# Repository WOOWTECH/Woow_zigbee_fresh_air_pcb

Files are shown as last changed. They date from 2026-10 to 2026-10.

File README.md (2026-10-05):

# Woow Zigbee 新風控制器 PCB（WO_30109）



220V 供電、4 路繼電器輸出的 Zigbee 新風（換氣扇）控制板。V3.0 起由一顆 **ESP32-C6** 同時負責 Zigbee 3.0 連網與控制，433MHz 遙控由 **SYN480R** 接收、ESP32 解碼（V2.0 以前是 STM32F103＋Tuya ZS3L＋EPA09-4D 模組）。

這個 repo 是把原設計 **V1.3**（Altium，外包設計）完整轉成 **KiCad 10**，用 git 做版控，並在 **V2.0** 修掉安規問題。

| 版本 | 狀態 | 說明 |
|---|---|---|
| `v1.3` | 參考用，**不可量產** | 原設計忠實重繪（原理圖＋PCB）。市電與低壓 GND 只隔 0.127mm。（`v1.3-baseline` 只含原理圖） |
| `v2.0` | **DRC 0 錯誤**（已合併 `main`） | 市電隔離 ≥6.4mm、保險絲＋壓敏電阻、降壓電源、Zigbee 串口 |
| `v3.0` | ERC/DRC 0；韌體 CI 綠燈 | ESP32-C6 單晶片 Zigbee＋SYN480R 433MHz，全部主料 JLC 可貼；市電區沿用 V2.0。見 [CHANGELOG](CHANGELOG.md#30--esp32-c6-單晶片syn480r) |
| `v3.4` | **目前版本**（ERC/DRC 0），**待打樣實測** | 照外殼 4-02-3（88×72×59 導軌盒）放回原板框：DI 2.54mm、NFC 外接 FPC 天線、P2 改測試點。見 [V3.4 驗證報告](docs/verification/V3.4.md) |
| `v3.3` | ⛔ 放不進外殼（板子加高到 107mm） | 加 NFC 設定介面（ST25DV04KC＋板上印刷線圈），J5 改到左側板邊。見 [V3.3 驗證報告](docs/verification/V3.3.md) |
| `v3.2` | ⛔ 放不進外殼（板子加高到 93mm） | 上緣左半段加長 10mm（L 形）加 4 路光耦 DI（乾接點／5–24VDC，NPN／PNP）、拿掉指撥。見 [V3.2 驗證報告](docs/verification/V3.2.md)（含 J5 接線） |
| `v3.1` | 只換值、不改佈線；ERC/DRC 0 | 433 匹配重新選值（失配 8–13dB → 3–5.3dB）、繼電器 PWM 降壓保持（取消 ≤3 顆限制）、續流改 Schottky、CPL 角度修正。見 [V3.1 驗證報告](docs/verification/V3.1.md) |

| V3.0 正面（零件面） | V3.0 背面 |
|---|---|
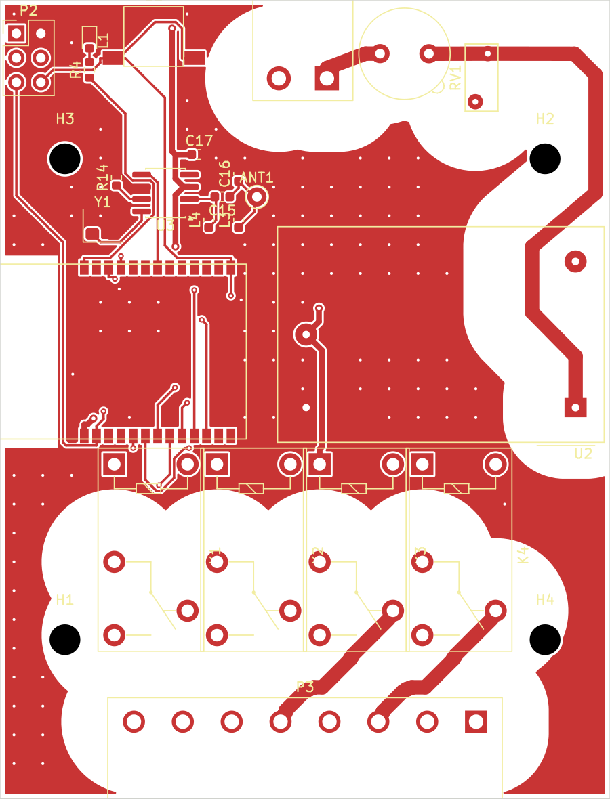
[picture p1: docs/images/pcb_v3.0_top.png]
PCB V3.0 正面
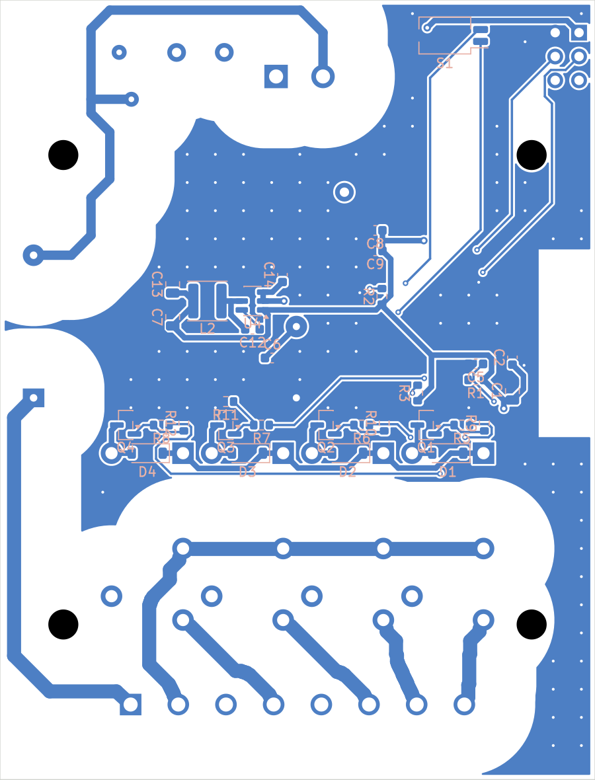
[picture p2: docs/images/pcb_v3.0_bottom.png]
PCB V3.0 背面
|  |  |

背面圖中藍色是 GND 鋪銅，白色帶是市電周圍 6.4mm 的安全帶（DRC 規則自動退讓）。完整原理圖：[V3.0](docs/images/schematic_v3.0.png)／[V2.0](docs/images/schematic_v2.0.png)。V3.0 左緣是 ESP32-C6 模組（天線端下方禁銅），左上是 SYN480R 433MHz 接收。

---

## 目錄

- [電路架構](#電路架構)
- [V1.3 → V2.0 改了什麼](#v13--v20-改了什麼)
- [安規隔離設計](#安規隔離設計)
- [Repo 結構](#repo-結構)
- [怎麼改設計（範例）](#怎麼改設計範例)
- [版本控制流程](#版本控制流程)
- [自動檢查（CI）](#自動檢查ci)
- [設計驗證報告](docs/verification/README.md)
- [主要料件](#主要料件)
- [已知限制與待辦](#已知限制與待辦)

---

## 電路架構

（V3.0；V2.0 以前低壓區是 STM32F103＋Tuya ZS3L＋EPA09-4D）

```mermaid
flowchart LR
    subgraph MAINS["⚡ 市電區（230VAC）"]
        P1["P1 市電輸入<br/>L / N"] --> F1["F1 保險絲<br/>T3.15A"]
        F1 --> RV1["RV1 壓敏電阻<br/>07D471K"]
        F1 --> IRM["U2 IRM-02-12<br/>AC→12V 2W<br/>（4.2kV 隔離）"]
        F1 -->|"P3.1 AC_L 輸出"| P3
        K["K1–K4 繼電器接點<br/>COM / NO / NC"] --> P3["P3 8P 輸出端子<br/>接風扇／閥"]
    end
    subgraph SELV["🔋 低壓區（12V / 3.3V）"]
        IRM -->|"+12V"| BUCK["U4 AP63203<br/>12V→3.3V 降壓"]
        IRM -->|"+12V"| COIL["繼電器線圈<br/>Q1–Q4 Si2302 驅動"]
        BUCK -->|"+3V3"| MCU["U1 ESP32-C6-WROOM-1<br/>Zigbee 3.0＋控制（V3.0）"]
        BUCK --> RF["U3 SYN480R<br/>433MHz ASK 接收"]
        ANT["ANT1 17.3cm 天線"] --> RF
        RF -->|"RF_DATA → IO23<br/>韌體解 EV1527"| MCU
        MCU -->|"Relay_1–4（IO6/7/0/1）"| COIL
        UI["B1 按鍵(IO9 BOOT) / S1 指撥 / L1 燈 / P2 燒錄座"] --- MCU
    end
    COIL -.->|"線圈-接點 加強絕緣"| K
```

### 電源預算（12V，IRM-02-12 額定 167mA）

| 負載 | V1.3 | V2.0 |
|---|---|---|
| 4 顆繼電器全吸（33.3mA × 4） | 133mA | 133mA |
| 3.3V 側（約 40mA） | 線性穩壓：12V 端也是 ~45mA | 降壓：12V 端約 13mA |
| **合計** | **~178mA（超過額定）** | **~146mA（在額定內）** |

---

## V1.3 → V2.0 改了什麼

```mermaid
flowchart TB
    A["V1.3 問題"] --> B1["市電離 GND 鋪銅 0.127mm"]
    A --> B2["AC 入口沒保險絲、沒壓敏電阻"]
    A --> B3["LM1117 線性穩壓：發熱、MLCC 不穩、12V 預算超標"]
    A --> B4["ZS3L 只用 GPIO，UART 沒接"]
    B1 --> C1["DRC 規則：市電↔低壓 ≥6.4mm<br/>鋪銅自動退讓、低壓元件移出安全帶"]
    B2 --> C2["F1 T3.15A ＋ RV1 07D471K"]
    B3 --> C3["AP63203 同步降壓（陶瓷電容穩定、耐 32V）"]
    B4 --> C4["TXD→PA10、RXD←PA9、RST←PB1"]
```

完整清單見 [CHANGELOG.md](CHANGELOG.md)，原設計審查見 [docs/review](docs/review)。

---

## 安規隔離設計

依 IEC 60664-1（230VAC、過電壓類別 II、汙染等級 2）設定，寫在 [`WO30109_FreshAir.kicad_dru`](hardware/WO30109_FreshAir/WO30109_FreshAir.kicad_dru)，KiCad DRC 與鋪銅都會自動遵守：

| 位置 | 要求 | V1.3 實測 | V2.0 |
|---|---|---|---|
| 市電 ↔ 低壓（含 GND 鋪銅） | ≥ 6.4mm（加強絕緣；與 G5Q 繼電器本身設計值相同） | **0.127mm** | ≥ 6.4mm |
| 市電不同網路之間（L-N、各路輸出） | ≥ 1.5mm（功能絕緣；G5Q 相鄰接點腳本身 1.67mm） | 0.5mm | ≥ 1.5mm |
| 銅到板邊 | ≥ 0.5mm | 0.26mm | ≥ 0.5mm |
| 固定孔（非金屬化）到市電 | ≥ 2.3mm（M3 螺絲頭多出孔外 1.15mm＋餘量）；**須用尼龍螺絲** | 1.77mm | 2.40–2.90mm |

```mermaid
flowchart LR
    L["市電銅箔<br/>AC_L / AC_N / DO_*"] ---|"≥ 1.5mm"| L2["另一條市電銅箔"]
    L ---|"≥ 6.4mm 安全帶<br/>（不得有任何低壓銅）"| S["低壓銅箔<br/>GND / 3.3V / 12V / 訊號"]
```

**怎麼確認**：在 KiCad 開 PCB → 檢查 → 設計規則檢查（DRC），或命令列：

```bash
kicad-cli pcb drc --severity-error hardware/WO30109_FreshAir/WO30109_FreshAir.kicad_pcb
```

---

## Repo 結構

```text
.
├── hardware/
│   ├── WO30109_FreshAir/          # KiCad 專案（用 KiCad 10 開 .kicad_pro）
│   │   ├── WO30109_FreshAir.kicad_sch   # 原理圖（由 scripts 產生）
│   │   ├── WO30109_FreshAir.kicad_pcb   # PCB
│   │   ├── WO30109_FreshAir.kicad_dru   # 安規 DRC 規則
│   │   ├── WO30109_FreshAir.kicad_jobset # 一鍵產出（ERC/DRC/Gerber/BOM/STEP）
│   │   └── sym-lib-table / fp-lib-table # 指向 ../lib 的專案庫
│   └── lib/
│       ├── WOOW.kicad_sym         # 自訂符號：ZS3L、EPA09-4D
│       ├── WOOW.pretty/           # 自訂封裝（焊盤量測自原板）
│       └── WOOW.3dshapes/         # 自訂 3D 模型
├── docs/verification/             # 設計驗證報告
├── scripts/
│   ├── design.py                  # ★ 電路唯一來源：零件、腳位、網路、改版差異
│   ├── gen_schematic.py           # design.py → .kicad_sch
│   ├── make_footprints.py         # 產生 WOOW.pretty
│   ├── import_v13_pcb.py          # 原 Gerber → KiCad PCB（需原始 Gerber，不公開）
│   ├── upgrade_v20_pcb.py         # V2.0 擺件與市電入口走線
│   ├── mains_router.py            # 雙層格點佈線器（市電間 1.5mm、對低壓 6.4mm）
│   ├── route_v20.py               # Freerouting 低壓佈線 + 鋪銅
│   ├── route_leftovers.py         # 補繞 Freerouting 沒繞通的線
│   ├── build_v20.sh               # ★ 一鍵重建 V2.0 PCB
│   ├── build_v30.sh               # ★ 一鍵重建 V3.0 PCB（從標籤 v2.0）
│   ├── build_v34.sh               # ★ 一鍵重建 V3.4 PCB（目前版本；從 V3.1 換件擺件 → Freerouting）
│   ├── upgrade_v34_pcb.py         # V3.4 換件、擺件、套網表、拆低壓走線
│   ├── upgrade_v32_pcb.py         # V3.2／V3.3 PCB（已作廢：放不進外殼）
│   ├── nfc_coil.py                # NFC 印刷線圈電感與調諧電容計算
│   ├── make_jlc_files.py          # ★ JLC 下單檔：Gerber zip、BOM、CPL（含 JLC 旋轉修正）
│   ├── drc_summary.py             # DRC 結果摘要
│   ├── add_stitching.py           # GND 縫合過孔
│   ├── make_3d_models.py          # 自訂零件 3D 模型（STEP）
│   └── assign_3d.py               # 3D 模型掛到封裝
├── sim/                           # SPICE 模擬（ngspice）
├── docs/review/                   # 設計審查報告
├── .github/workflows/kicad-ci.yml # 自動 ERC / DRC / 生產檔
├── CHANGELOG.md
└── README.md
```

---

## 怎麼改設計（範例）

原理圖由 `scripts/design.py` 產生，**改電路請改 design.py，不要直接在 KiCad 手改原理圖**（下次產生會被蓋掉）。PCB 可以直接在 KiCad 改。

### 範例 1：把 R4（LED 限流）從 100Ω 改成 220Ω

```python
# scripts/design.py
add("R4", "Device:R", "220R", R0603, "C22962", {"1": led_net, "2": "LED_A"})
```

```bash
python scripts/gen_schematic.py 2.0          # 重新產生原理圖
kicad-cli sch erc hardware/WO30109_FreshAir/WO30109_FreshAir.kicad_sch
# 開 KiCad PCB → 工具 → 從原理圖更新 PCB（F8）
git switch -c fix/led-resistor
git commit -am "fix: R4 改 220R，降低 LED 亮度"
git push -u origin fix/led-resistor && gh pr create
```

### 範例 2：在 KiCad 圖形介面裡用 Git

KiCad 9 起專案管理器內建 Git（檔案樹會顯示修改狀態、可 commit / push / pull / 切分支）。KiCad 9.0.0 的 push/pull 帳密處理曾有回報問題，建議 commit 用 KiCad、push 用命令列或 `gh`：

1. 用 KiCad 開 `hardware/WO30109_FreshAir/WO30109_FreshAir.kicad_pro`
2. 左側檔案樹按右鍵 → **Git** → Commit / Push / Switch branch
3. 偏好設定 → Version Control 可設定作者與遠端更新頻率

### 範例 3：重建整片 V2.0 PCB

```mermaid
flowchart LR
    A["原 V1.3 Gerber<br/>（不公開）"] --> B["import_v13_pcb.py<br/>銅箔→KiCad、焊盤對位"]
    D["design.py<br/>V2.0 網表"] --> B
    B --> C["upgrade_v20_pcb.py<br/>擺件、市電入口"]
    C --> E["mains_router.py<br/>繼電器輸出 DO_*"]
    E --> F["Freerouting<br/>低壓網路"]
    F --> G["route_leftovers.py<br/>補線"]
    G --> H["鋪銅（DRC 規則退讓）"]
    H --> I["DRC 0 錯誤"]
```

```bash
# 需要 KiCad 10、Java 17、xvfb-run、Freerouting 1.9 jar、kicad-sch-api
ORIG_GERBER=/path/to/V1.3_gerber ./scripts/build_v20.sh
```

Freerouting 每次結果不完全一樣；跑完一定看最後的 DRC 摘要，`errors: {}` 且 `unconnected: 0` 才算成功。

---

## 版本控制流程

```mermaid
gitGraph
    commit id: "V1.3 原理圖重繪" tag: "v1.3-baseline"
    commit id: "V1.3 PCB 轉入 + 安規規則" tag: "v1.3"
    branch rev/v2.0
    checkout rev/v2.0
    commit id: "原理圖：保險絲/降壓/UART"
    commit id: "PCB：擺件、市電佈線、低壓自動佈線（DRC 0 錯）"
    checkout main
    merge rev/v2.0 tag: "v2.0"
    branch fix/xxx
    commit id: "小修正"
    checkout main
    merge fix/xxx
```

| 規則 | 說明 |
|---|---|
| `main` | 永遠是可以生產的狀態（CI 綠燈） |
| `rev/vX.Y` | 一次改版一個分支，完成後開 PR 合併 |
| `fix/…`、`feat/…` | 小修改 |
| 標籤 `vX.Y` | 送廠的版本；Gerber、BOM、座標檔附在 GitHub Release |
| commit 訊息 | `feat:` 新功能、`fix:` 修正、`docs:` 文件，內文寫「改了什麼、為什麼」 |

**為什麼 KiCad 適合 git**：`.kicad_sch`、`.kicad_pcb`、`.kicad_sym`、`.kicad_mod` 都是純文字（S-expression），`git diff` 看得到每一行的變化；暫存檔（`*.kicad_prl`、`*-backups/`、`fp-info-cache`）已在 `.gitignore` 排除。要看圖形化差異可用 [KiRI](https://github.com/leoheck/kiri) 或 [kicadiff](https://github.com/sksat/kicadiff)。

---

## 自動檢查（CI）

每次 push 或開 PR，GitHub Actions（`kicad/kicad:10.0` 容器）會：

```mermaid
flowchart LR
    A["git push / PR"] --> B["ERC<br/>原理圖電氣規則"]
    B --> C["DRC<br/>佈線＋市電安規"]
    C --> D["產生生產檔<br/>Gerber / 鑽孔 / 座標 / BOM / PDF"]
    D --> E["Actions Artifacts<br/>下載送 JLC"]
```

任何 ERC/DRC **錯誤**都會讓 CI 變紅燈，不能合併到 `main`。CI 也會跑 SPICE（繼電器關斷尖峰必須 < 20V）並輸出 STEP 3D 檔。

本機一鍵產出（不需要 GitHub）：KiCad 專案管理器點 `WO30109_FreshAir.kicad_jobset`，或

```bash
cd hardware/WO30109_FreshAir && kicad-cli jobset run --file WO30109_FreshAir.kicad_jobset WO30109_FreshAir.kicad_pro
```

---

## 設計驗證

完整報告：**[V3.0](docs/verification/V3.0.md)**（ESP32-C6＋SYN480R，含電源預算、433 匹配模擬）／[V2.0](docs/verification/README.md)

| 項目 | 結果 |
|---|---|
| ERC／DRC（含市電安規）／parity | 0／0／0 |
| SPICE（ngspice） | 8 子電路全過；繼電器關斷尖峰 12.8V（拿掉續流二極體時 251V） |
| PCB 計算器（IPC-2221） | ⚠️ 市電 1.5mm 線在 1oz 銅剛好等於保險絲 3.15A；>3A 負載請選 2oz 銅 |
| 熱分析 | 最壞 2.6W；IRM-02 在此負載環境上限約 74°C |
| EMC 預檢 | 風險分數 49/100，多數為市電隔離的刻意設計；量產前需實測預掃 |
| 3D／STEP | 正面最高 16.9mm、背面 4.3mm；STEP 由 CI 產生 |
| Jobset | 8/8 工作成功（KiCad 原生一鍵產出） |

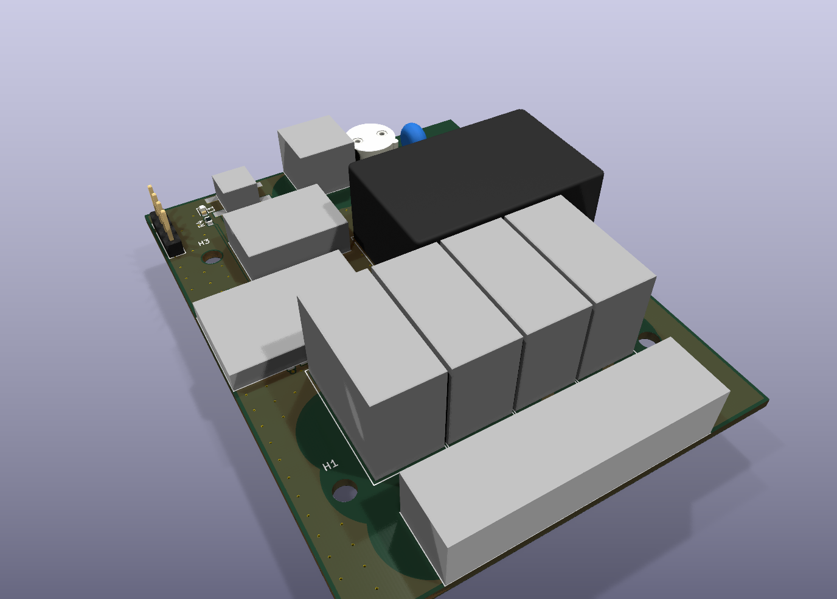
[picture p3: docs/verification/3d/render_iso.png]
3D


---

## 主要料件

| 位號 | 料件 | LCSC | 備註 |
|---|---|---|---|
| U1 | ESP32-C6-WROOM-1-N8（V3.0） | C5366877 | Zigbee 3.0／Wi-Fi 6／BLE 5，PCB 天線（V2.0：STM32F103C8T6 C8734） |
| U2 | MEAN WELL IRM-02-12 | C7211213 | 230VAC→12V 2W |
| U3 | SYN480R（V3.0） | C916347 | 433.92MHz ASK 接收；Y1 13.52127MHz C654957（V2.0：Tuya ZS3L，JLC 無料） |
| U4 | AP63203WU-7（V2.0） | C780769 | 12V→3.3V 降壓 |
| L2 | SWPA4030S3R9MT 3.9µH（V2.0） | C96899 | 規格書 Table 2 建議值 |
| K1–K4 | Omron G5Q-1 DC12 | C397244 | 250VAC：NO 5A、NC 3A |
| F1 | 保險絲 T3.15A 250V（V2.0） | — | TR5 座，手焊 |
| RV1 | 07D471K（V2.0） | C28756 | |
| ANT1 | 433MHz 1/4 波長天線（V3.0） | — | 17.3cm 導線或彈簧天線，手焊（V2.0：RF1 EPA09-4D，規格書未公開） |

完整 BOM 由 CI 產生（`*-bom.csv`）。

---

## DI 輸入接線（J5）

| J5 腳 | 1 | 2 | 3 | 4 | 5 | 6 | 7 |
|---|---|---|---|---|---|---|---|
| 名稱 | +12V（限流 8mA） | IN1 | IN2 | IN3 | IN4 | COM | GND |

V3.4 的 J5 在上緣開窗（P1 左邊），2.54mm 間距，**由左往右**是 1→7（電線最大 0.5mm²）。V3.3 直立在左側板邊（已作廢）。

- **乾接點**（按鈕、溫控器、門磁）：COM（6）接 GND（7），每個接點接在 +12V（1）和 INx 之間。
- **NPN 輸出**：COM 接外部 +5～24V，INx 接感測器輸出。
- **PNP 輸出**：COM 接外部 0V，INx 接感測器輸出。
- 光耦隔離 2.5kVrms；用乾接點接法時，外部線路和板子的 SELV 低壓共地。
- 細節見 [V3.2 驗證報告 §2](docs/verification/V3.2.md#2-j5-接線)。

## 外殼

精鋼塑模 **4-02-3**：35mm 導軌式開關盒，外形 88×72×59mm，ABS。板子用 4 根 M3 螺絲鎖在底座，間距 50×50mm。

- P1（AC IN）、J5（DI）從上方開窗出線；P3（AC OUT）從下方開窗出線。
- NFC：FPC 天線貼在前蓋凸起部位的內側，接到板上 J6。
- 固定螺絲用尼龍螺絲（市電對可觸及金屬要 6.4mm）。

## 已知限制與待辦

- **電源預算（V3.1）**：IRM-02-12 額定 167mA。韌體讓繼電器全壓吸合 100ms 後改 20kHz、60% PWM 保持（Omron G5Q-1 規定保持電壓 ≥30%），每顆 12V 端 33.3→14.4mA；4 顆可同時吸合，最壞（3 顆保持＋1 顆吸合＋發射峰值）約 135mA。V3.0 是韌體限制 ≤3 顆。標準版 G5Q-1 沒有 Omron 的 PWM 背書（只有 -PW 型有，JLC 無料），打樣要在最高溫實測保持與釋放。見 [V3.1 驗證報告](docs/verification/V3.1.md#2-電源繼電器-pwm-降壓保持)。
- **433MHz**：SYN480R 只輸出解調後的原始波形，遙控器編碼（EV1527／PT2262）要在 ESP32 韌體解。V3.0 的匹配值照規格書典型應用，但用同系列 Micrel 原廠實測輸入阻抗算，峰值落在 210–230MHz；V3.1 重新選值（同拓撲、同佈線）。晶片真實阻抗原廠沒公開，打樣後要用 VNA 量 S11 或遙控器實測距離微調。見 [V3.1 驗證報告](docs/verification/V3.1.md#1-433mhz-匹配)。
- **V3.0 ESP32 天線**：模組天線端貼左板邊、下方兩層禁銅；外殼若是金屬或天線端靠近金屬，Zigbee 距離會明顯縮短，必要時改外接天線版 ESP32-C6-WROOM-1U（腳位相同、本體短 6.3mm；2026-10-03 查 JLC 0 庫存，要客供）。
- **繼電器負載**：G5Q-1 在 250VAC 只有 NO 5A／NC 3A，沒有馬達額定；多段速風扇要在韌體互鎖，避免兩檔同時吸合。
- **固定孔一律用尼龍螺絲／絕緣支柱**：V2.0 孔邊到市電銅箔 2.4–2.9mm（DRC 規則 `hole_to_mains` ≥ 2.3mm），足夠避開螺絲頭，但達不到市電對可觸及金屬的 6.4mm，所以不能用金屬螺絲接金屬外殼。
- **韌體**：V3.0 韌體在 [`firmware/`](firmware/README.md)（ESP-IDF v5.5.4＋esp-zigbee-lib v2）：Zigbee 路由器 4 個開關端點、指撥 4 種模式與風速互鎖、EV1527 遙控器學習、按鍵／燈號。主機端單元測試與完整編譯都在 CI。實際入網與遙控器相容性要打樣後驗證。
- 原始 Altium 檔、Gerber、請款單等外包資料**不公開**，不在本 repo。

---

## 資料來源

- MEAN WELL IRM-02 規格書：<https://www.meanwell.com/Upload/PDF/IRM-02/IRM-02-SPEC.PDF>
- Omron G5Q：<https://omronfs.omron.com/en_US/ecb/products/pdf/en-g5q.pdf>
- Tuya ZS3L：<https://developer.tuya.com/en/docs/iot/zs3l?id=K97r37j19f496>
- Espressif ESP32-C6-WROOM-1 規格書 v1.4：<https://documentation.espressif.com/esp32-c6-wroom-1_wroom-1u_datasheet_en.pdf>
- JSMSEMI SYN480R 規格書：LCSC C916347
- Diodes AP63203：<https://www.diodes.com/assets/Datasheets/AP63200-AP63201-AP63203-AP63205.pdf>
- IEC 60664-1 間距表（TI SLUP421）：<https://www.ti.com/lit/pdf/SLUP421>
- KiCad Git 整合：<https://docs.kicad.org/9.0/en/kicad/kicad.html>

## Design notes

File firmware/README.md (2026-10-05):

# WO_30109 新風控制器韌體（ESP32-C6，V3.2 硬體）

ESP-IDF v5.5.4 ＋ esp-zigbee-lib v2（Espressif 自家 Zigbee 協定堆疊）。硬體見 [../README.md](../README.md)。

## 功能

| 功能 | 說明 |
|---|---|
| Zigbee 3.0 | **路由器**（市電供電，幫電池裝置中繼）。4 個端點 EP1–4，各是一個 *Mains Power Outlet*（On/Off 叢集）＝繼電器 1–4。Zigbee2MQTT／ZHA 會看到 4 個開關。 |
| DI／DO 模式（V3.2） | 4 路 DI（J5 光耦）＋433 遙控 4 鍵同步，固定 1 對 1 控制 K1–K4；模式見下節。設定存在 NVS（V3.2 拿掉指撥） |
| 互鎖 | 風速群組內「先斷後通」：關掉舊的一檔 → 等 200ms → 吸合新的一檔。協調器同時要求兩檔時，後到的贏，前一檔自動關並回報 |
| 電源保護 | 同時吸合上限（預設 3）、兩顆線圈吸合間隔 ≥50ms、802.15.4 發射 +10dBm、不啟動 Wi-Fi |
| 433MHz 遙控 | SYN480R → IO23 邊緣中斷 → EV1527 解碼（連續兩幀相同才算）。學過的遙控器 A/B/C/D 鍵＝DI1–DI4 的分身（同一組設定）。最多記 8 支，存在 NVS |
| 按鍵 B1 | 短按：風速循環（關→1→2→3→關；4 路模式＝切換繼電器 1）。按住 3–8 秒放開：學習遙控器 20 秒。按住 ≥10 秒放開：恢復出廠 |
| NFC 設定（V3.3） | U6 ST25DV04KC（I2C：IO20／IO19）。App 貼近板子讀寫 DI／DO 模式、點動時間、名稱、遙控器清單；每 100ms 輪詢晶片。寫入要附 HMAC 簽章（每台 8 位數 PIN，開機 log 會印），規格見 [docs/nfc-protocol.md](../docs/nfc-protocol.md) |
| 指示燈 L1 | 慢閃＝尚未入網；恆亮＝已入網；快閃＝學習模式（或按住 3–8 秒中）；按住超過 10 秒時恆亮＝放開就重置 |

### DI／DO 模式（V3.2，`components/fa_core/include/fa_io.h`）

每路 DI 和 DO 各自設定；DI k（J5 的 INk 或遙控器第 k 鍵，任一接通就算接通）控制繼電器 Kk。

| DO＼DI | 全關 | 按一次（接通那一刻） | 持續（接通期間） |
|---|---|---|---|
| **自鎖** | 不動作 | 開↔關反轉 | 接通＝開、斷開＝關 |
| **點動** | 不動作 | 開「點動時間」後自動關（期間再按重新計時） | 接通＝開、斷開＝關 |
| **互鎖** | 不動作 | 沒開就開（同組其他先關，間隔 200ms）、已開就關 | 接通＝開（同組其他先關）、斷開＝關 |

- 設成「互鎖」的幾路自動成一組，取代 V3.0 的指撥風速模式；按鍵短按的風速循環也以這組為準。
- 接線 DI 每 10ms 取樣，連續 30ms 相同才算（板上另有 10nF＋內建上拉約 0.45ms 濾波）。
- 遙控器沒有放開訊號：按住時每 40–64ms 重送一幀，超過 200ms 沒收到就當放開，所以遙控器也能用「持續」模式（按住才開）。
- Zigbee 指令與按鍵直接操作繼電器（遵守互鎖與同時吸合上限），最後的指令為準。
- 出廠預設（menuconfig「出廠預設 DO／DI 模式」）：三段風速＋1 路（K1–K3 互鎖、K4 自鎖）、DI 全部「持續」、點動 1 秒。
  設定存在 NVS `fa/io_cfg`；V4（Matter）會從 Home Assistant 下拉選單與維護網頁寫入。恢復出廠會清掉。

### 電源預算（為什麼預設值這樣設）

IRM-02-12 額定 12V 167mA，超過 110%（約 184mA）進保護。

| 負載 | 3.3V 側 | 換到 12V 側（降壓效率 88%） |
|---|---|---|
| ESP32-C6 802.15.4 收訊（路由器常態） | 73mA | 23mA |
| SYN480R＋LED＋其他 | ~9mA | 3mA |
| 4 顆 G5Q 線圈 | — | 133mA |
| **4 顆全吸，持續** | | **159mA（95%）** |
| 發射 +10dBm 峰值（毫秒級，規格書 0/+12dBm 內插 ≈174mA） | +~100mA | +~32mA |

**V3.1：PWM 降壓保持（預設開）。** 每顆線圈先全壓 `FA_RELAY_PULLIN_MS`（100ms，Omron 規定 ≥100ms），
之後用 LEDC 以 20kHz、60% duty 保持；D1–D4 續流（V3.1 改 B5819W），線圈平均 7.66V（額定 64%，Omron 要求 ≥30%），
12V 端每顆 33.3→14.4mA（`sim/relay_pwm_hold.cir`）。吸合錯開 110ms，同時最多 1 顆在全壓。

| 情況 | 12V 側 | 判定 |
|---|---|---|
| 4 顆保持＋發射峰值 | 26＋32＋4×14.4 ≈ 116mA | 額定 70% |
| 3 顆保持＋1 顆吸合＋發射峰值（最壞） | 26＋32＋3×14.4＋33.3 ≈ 135mA | 額定 81% |
| 關掉 PWM（V3.0 行為）：4 顆＋發射峰值 | 191mA | 超過 110% 保護點 → 上限 3 |

`FA_MAX_RELAYS_ON` 開 PWM 時預設 4、關掉時預設 3；關掉 PWM 卻設 4、或吸合間隔 ≤ 吸合時間，會直接**編譯失敗**（`main/app_main.c` 的 `#error`）。
標準版 G5Q-1 沒有 Omron 的 PWM 背書（只有 -PW 型有，JLC 無料），打樣要在最高環境溫度下實測保持與釋放。

## 建置

```bash
. ~/esp/esp-idf-v5.5.4/export.sh
cd firmware
idf.py set-target esp32c6     # 第一次
idf.py build
```

設定（`idf.py menuconfig` → *WO30109 新風控制器*）：同時吸合上限、發射功率、互鎖間隔、吸合間隔。

### 燒錄

P2 2×3 排針：1 3V3、2 GND、3 TXD0、4 RXD0、5 EN、6 BOOT(IO9)。接 USB-UART 轉接板（含 DTR/RTS 自動下載電路）就能直接燒；沒有自動電路時，按住 B1 再上電即進下載模式。

```bash
idf.py -p /dev/ttyUSB0 flash monitor
```

⚠️ **燒錄時不要接 230V**。板子低壓區與市電隔離，但轉接板和電腦接地會變成另一條路徑；要邊通市電邊看 log 請用隔離型 USB-UART。

## 單元測試（不需要 ESP-IDF）

純邏輯在 `components/fa_core/`（繼電器互鎖、EV1527 解碼、按鍵、遙控器表），用主機 gcc 加 AddressSanitizer／UBSan 測：

```bash
make -C firmware/test
```

CI 每次 push 都會跑單元測試，並用 `espressif/idf:v5.5.4` 容器編譯整個韌體。

## 檔案

```text
firmware/
├── main/
│   ├── app_main.c        # GPIO、繼電器執行緒、433 中斷、按鍵／燈號、NVS
│   ├── fa_zigbee.c/.h    # Zigbee 路由器、4 個 On/Off 端點、配網、恢復出廠
│   ├── board.h           # 腳位（與 scripts/design.py 一致；menuconfig 選板子版本 V3.3／V3.2）
│   ├── st25dv.c/.h       # ST25DV04KC I2C 驅動（EEPROM、動態暫存器、mailbox）
│   ├── fa_nfc_port.c/.h  # NFC 設定介面：驗證並套用 REQUEST、回答 mailbox、寫 STATE
│   └── Kconfig.projbuild # 可調參數
├── components/fa_core/   # 純 C 邏輯（主機可測）
└── test/                 # 主機端單元測試
```

## 尚未驗證（要打樣後做）

- 實際入網（Zigbee2MQTT／ZHA）、4 個端點命名與回報。
- 433 解碼對實際遙控器的相容性：只支援 **EV1527 學習碼**（市售 433 遙控器最常見）；PT2262 固定碼與滾碼遙控器不支援。按鍵對應假設 A/B/C/D = 0x8/0x4/0x2/0x1，部分品牌不同時要改 `fa_remote_key_to_channel()`。
- SYN480R 關閉靜噪（R14 = 0R）時 DO 腳會持續輸出雜訊，中斷量要實測；太高可改成 R14 不上件（開靜噪，靈敏度少 3dB）。

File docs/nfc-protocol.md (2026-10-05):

# WO30109 NFC 設定協定 v1（給 App 開發）

適用板子 V3.3 起（U6 ST25DV04KC）。App 貼近板子即可讀寫進階設定，不需要任何網路。

- **板子有沒有通電都能讀寫**：斷電時晶片靠手機 NFC 場供電，可以讀寫 EEPROM；設定會在下次開機套用。
- **mailbox 即時指令**：要板子通電才能用。

- **參考實作**：[`tools/nfc_ref.py`](../tools/nfc_ref.py)，只用 Python 標準函式庫，可以直接照著翻成 Swift／Kotlin。
- **韌體實作**：`firmware/components/fa_core/src/fa_nfc.c`。
- **測試向量**：兩份實作用同一組向量逐 byte 對照（§7）。App 也請用同一組向量做單元測試。

## 1. 晶片與 NFC 指令

| 項目 | 值 |
|---|---|
| 標準 | ISO/IEC 15693（NFC Forum Type 5） |
| iOS | Core NFC `NFCTagReaderSession(pollingOption: .iso15693)` → `NFCISO15693Tag` |
| Android | `NfcV`（`android.nfc.tech.NfcV`） |
| 區塊大小 | 4 bytes；使用者 EEPROM 共 128 塊（512 bytes） |
| 製造商代碼（IC Mfg code） | `0x02`（ST），自訂指令要帶 |

使用的 ISO 15693 指令（規格書 DS13519 Rev 4 §7.6.8、§7.6.12、§7.6.31–33；ST 自訂指令都要帶 IC Mfg code `0x02`）：

| 用途 | 指令 | 備註 |
|---|---|---|
| 讀多個區塊 | `0x23` Read Multiple Blocks | iOS：`readMultipleBlocks` |
| 寫單一區塊 | `0x21` Write Single Block | iOS：`writeSingleBlock`；每塊約 5ms |
| 讀 mailbox 長度 | `0xAB` Read Message Length（ST 自訂） | 回傳值＝長度−1 |
| 讀 mailbox | `0xAC` Read Message（ST 自訂） | 參數：MBPointer `00`、Number of bytes `00` → 回傳整則訊息 |
| 寫 mailbox | `0xAA` Write Message（ST 自訂） | 參數：MSGLength（長度−1）、資料；要等 HOST_PUT_MSG＝0（上一則回覆已讀走）才能寫 |
| 讀 mailbox 狀態 | `0xAD` Read Dynamic Configuration，位址 `0x0D`（MB_CTRL_Dyn） | bit1 HOST_PUT_MSG＝板子有回覆 |

iOS 用 `customCommand(requestFlags:customCommandCode:customRequestParameters:)` 送 0xAA–0xAD；Android 用 `NfcV.transceive()`，自行組 `flags, cmd, 0x02, params`。

## 2. EEPROM 配置（使用者記憶體）

| 位址（byte） | 區塊 | 內容 | 誰寫 |
|---|---|---|---|
| `0x000`–`0x03F` | 0–15 | 保留（之後放 NDEF：貼手機就開 App 下載頁） | — |
| `0x040`–`0x0DF` | 16–55 | **STATE**：目前設定 | ESP32 |
| `0x0E0`–`0x17F` | 56–95 | **REQUEST**（App 寫）／**ACK**（ESP32 回寫） | App ↔ ESP32 |
| `0x180`–`0x1FF` | 96–127 | 保留 | — |

所有多位元組欄位都是 **little-endian**。

### 2.1 共用標頭（12 bytes）

| 偏移 | 長度 | 欄位 | 值 |
|---|---|---|---|
| 0 | 2 | magic | `'W' 'O'`（`57 4F`） |
| 2 | 1 | type | 1＝STATE、2＝REQUEST、3＝ACK |
| 3 | 1 | version | 1 |
| 4 | 4 | gen | 設定代數（見 §3） |
| 8 | 2 | len | 標頭後面的內容長度 |
| 10 | 2 | flags | 0 |

### 2.2 設定內容（payload，84 bytes）

| 偏移 | 長度 | 欄位 | 說明 |
|---|---|---|---|
| 0 | 4 | di_mode[4] | 每路 DI：0 全關、1 按一次、2 持續 |
| 4 | 4 | do_mode[4] | 每路 DO：0 自鎖、1 點動、2 互鎖（設成互鎖的幾路自動成一組） |
| 8 | 16 | jog_ms[4] | u32，點動時間（ms），500–3,600,000 |
| 24 | 24 | name | UTF-8 裝置名稱，0 結尾，最多 23 bytes |
| 48 | 1 | n_remotes | 已學習的 433 遙控器數量（0–8） |
| 49 | 3 | — | 0 |
| 52 | 32 | remotes[8] | u32，EV1527 20 位元位址；只有前 n_remotes 個有效，其餘填 0 |

### 2.3 STATE（`0x040`，106 bytes）

`標頭(type=1, len=92)` ＋ `payload(84)` ＋ `fw_version u32`（0x00MMmmpp，例如 3.3.0＝`0x00030300`）＋ `hw_rev[4]`（ASCII，例如 `"3.3\0"`）＋ `crc16 u16`。

- **CRC**：對前 104 bytes 計算 **CRC-16/CCITT-FALSE**（多項式 0x1021、初值 0xFFFF、不反射、不 XOR；`"123456789"` → `0x29B1`）。
- **CRC 不符**：可能剛好讀到 ESP32 正在寫的半筆，請重讀。
- **ESP32 什麼時候重寫 STATE**：每次開機、每次設定改變後。

### 2.4 REQUEST（`0x0E0`，112 bytes）

`標頭(type=2, gen=所根據的 STATE.gen, len=84)` ＋ `payload(84)` ＋ `tag(16)`

- **tag**：`HMAC-SHA256(key, 前 96 bytes)` 的前 16 bytes。
- **key**：`SHA-256("WO30109-NFC-v1:" + PIN)`。PIN 是 8 位數字的 ASCII，印在機器標籤上（§5）。
- **寫入順序很重要**：先寫區塊 57–83（位址 `0x0E4` 起，也就是第 4 byte 以後的所有內容），**最後才寫區塊 56**（magic／type／version 所在的 `0x0E0`–`0x0E3`）。ESP32 只要看到 magic 和 type=2，就當作整筆已經寫完。
- **最後一塊不足 4 bytes**：補 0。112 bytes 剛好 28 塊，不用補。

### 2.5 ACK（`0x0E0`，16 bytes）

ESP32 處理完 REQUEST（每 100ms 檢查一次）後，會在同一個位置寫入：

`標頭(type=3, gen=REQUEST 所根據的 gen, len=4)` ＋ `status u8` ＋ `0 0 0`

| status | 意義 | App 該怎麼做 |
|---|---|---|
| 0 | OK，已套用 | 重讀 STATE（gen 會＋1） |
| 1 | 簽章錯 | PIN 不對（或資料傳輸出錯） |
| 2 | gen 不符 | 設定在這之間被別處改過：重讀 STATE、讓使用者確認後再送 |
| 3 | 欄位不合法 | 模式超出範圍、點動時間超出範圍、名稱沒有 0 結尾，或遙控器清單裡有沒學過的位址 |
| 4 | 格式錯 | magic／type／version／len 不對 |

**板子沒通電時**：寫進去的 REQUEST 會留在 EEPROM，下次開機才處理。App 可以顯示「已寫入，下次通電時套用」。

## 3. gen（設定代數）與重送保護

- STATE.gen 每次設定改變就＋1。改變的來源包括：NFC、遙控器學習、恢復出廠，以及之後的 Matter／HA。
- REQUEST 必須帶「讀到的 STATE.gen」。ESP32 只接受 `REQUEST.gen == 目前 gen`。
- 所以：
  - **錄下來的舊請求重送無效**：gen 已經往前了。
  - **不會蓋掉別人剛改的設定**：樂觀鎖。
- 恢復出廠**不會**把 gen 歸零。

## 4. mailbox 即時指令（板子要有電）

### 4.1 流程

1. 讀 `MB_CTRL_Dyn`，確認 mailbox 已開啟（bit0 MB_EN＝1）。
2. 用 Write Message（`0xAA`）寫入請求。
3. 每 20–50ms 讀一次 `MB_CTRL_Dyn`，等 bit1 HOST_PUT_MSG＝1（ESP32 每 100ms 輪詢一次）。
4. 用 Read Message Length（`0xAB`）＋ Read Message（`0xAC`）讀回覆。

### 4.2 格式

| 方向 | 格式 |
|---|---|
| App → 板子 | `'M'(4D)` `cmd` `seq` `len` `payload[len]` ［`tag16`，只有需授權的指令］ |
| 板子 → App | `'R'(52)` `cmd` `seq` `status` `len` `payload[len]` |

- **需授權指令的 tag**：`HMAC-SHA256(key, 'M' cmd seq len payload ‖ challenge(u32 LE))` 的前 16 bytes。
- **challenge**：由 GET_STATUS 的回覆取得；**每次 GET_STATUS 都會換新**。授權指令不論成功或失敗，用過一次就作廢。所以要先 GET_STATUS，再送授權指令。

| cmd | 名稱 | 授權 | 回覆內容 |
|---|---|---|---|
| `0x01` | GET_STATUS | 不需要 | 20 bytes（見下表） |
| `0x02` | IDENTIFY | 不需要 | 無；LED 快閃 5 秒，用來找是哪一台 |
| `0x10` | LEARN_REMOTE | 需要 | 無；進入遙控器學習 20 秒（按遙控器任一鍵完成，STATE 隨後更新） |
| `0x7F` | FACTORY_RESET | 需要 | 無；回覆後 0.5 秒重置並重開機 |

**GET_STATUS 回覆內容（20 bytes）**

| 偏移 | 長度 | 欄位 |
|---|---|---|
| 0 | 4 | gen |
| 4 | 1 | relays：bit k＝K(k+1) 吸合 |
| 5 | 1 | di：bit k＝DI(k+1) 接通（接線或遙控器） |
| 6 | 1 | net：0 未入網、1 已入網 |
| 7 | 1 | flags：bit0 遙控器學習中 |
| 8 | 4 | fw_version |
| 12 | 4 | uptime_s |
| 16 | 4 | challenge |

status 碼和 §2.5 相同，另外 5＝未知指令。

## 5. PIN 與安全性

- **PIN 怎麼來**：每台 8 位數，第一次開機用硬體亂數產生、存在 NVS，恢復出廠也保留。開機 log 會印 `NFC 就緒：UID …，PIN xxxxxxxx`。
- **產線**：燒錄後讀 log，把 PIN 印在標籤上（例如做成 QR code，內容 `WO30109:<UID>:<PIN>`，App 掃一次就記住）。
- **V4（Matter）**：改用 Matter 配對碼，不再另外印。
- **為什麼不用晶片的 RF 密碼**：ST25DV 的 RF 密碼 I2C 端無法設定（規格書 Table 60 寫明 I2C「No access」），只能由手機端寫入，產線就得逐台用手機設密碼。所以改由 ESP32 驗簽：
  - **讀取不設限**：STATE 裡沒有機密資料。
  - **寫入要簽章**：誰都能寫 EEPROM，但只有帶正確簽章、而且根據最新 gen 的 REQUEST 才會被套用；其他寫入會收到 ACK 錯誤碼，下次開機 STATE 也會被重寫回正確內容。
  - **遙控器只能刪、不能加**：加入新遙控器一定要在現場學習（按鍵或 LEARN_REMOTE 指令），避免用 NFC 偷偷塞一支別人的遙控器。
- **限制**：
  - 拿到 PIN 的人可以改設定，所以 PIN 要當成和 Wi-Fi 密碼一樣的東西保管。
  - 8 位數 PIN 的 key 理論上可以離線暴力破解（拿一筆合法的 REQUEST 去試 10⁸ 個 PIN）。設定介面的風險可以接受；V4 改用 Matter 配對碼時，一併評估是否改用更長的 key。

## 6. App 建議流程

1. **連線**：掃描到 ISO 15693 標籤，UID 以 `E0 02` 開頭（ST）。
2. **讀狀態**：讀區塊 16–42（`0x040` 起 108 bytes）→ 解析 STATE；CRC 錯就重讀。
3. **板子有電時**：顯示即時狀態，送 GET_STATUS 取得繼電器／DI 狀態和 challenge。
4. **送出設定**：使用者修改後組 REQUEST（gen＝剛讀到的 STATE.gen）→ 先寫區塊 57–83，最後寫區塊 56。
5. **確認結果**：每 100ms 讀一次區塊 56–59（16 bytes），等 type＝3 的 ACK：
   - status＝0：重讀 STATE 並顯示「已套用」；
   - 板子沒電、一直等不到 ACK：顯示「已寫入，下次通電時套用」。

## 7. 測試向量（App 單元測試請比對）

輸入：

- PIN `12345678`
- di＝[2, 1, 0, 2]
- do＝[2, 2, 1, 0]
- jog_ms＝[1000, 1000, 5000, 1000]
- name＝「客廳新風」
- remotes＝[0x3A5F2, 0x1B007]

```text
key        af10885190a690551f30c392e3a2ac903d49c777af07f01f09e12ae1cd47c78f
REQUEST    （gen 7）
           574f020107000000540000000201000202020100e8030000e803000088130000e8030000e5aea2e5bbb3e696b0e9a2a8
           00000000000000000000000002000000f2a5030007b00100000000000000000000000000000000000000000000000000
           975e9f95241f9ba804233e515be1fba9
STATE CRC  （gen 8、fw 0x00030301、hw "3.3"）前 104 bytes 的 CRC-16 = 0xca77
LEARN_REMOTE（seq 5、challenge 0xDEADBEEF）
           4d100500636fc02e061f09f2b9b375043c1bd0d2
```

產生方式：`python3 tools/nfc_ref.py`。韌體對應的測試是 `firmware/test/test_core.c` 的 `nfc_cross_language_vectors`。

## 8. 版本相容

- `version` 欄位目前是 1。之後擴充 payload 時會改成 2，並保留讀 v1 的能力。
- App 遇到 version 比自己認得的新，請只讀、不寫。

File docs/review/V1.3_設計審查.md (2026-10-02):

# WO_30109 Zigbee 新風控制器 — 完整分析報告（2026-10-02）

資料：Odoo 任務 94 的原理圖（2025-08-28）、Gerber/座標 V1.3、BOM V1.0（過時）。
方法：KiCad 10 重建板子跑 DRC；直接解析 Gerber 銅箔（含鋪銅）算連通與間隙；零件規格書與安規資料由網路一手來源查證（來源見文末）。

## 🔴 嚴重（量產前必改）
1. **市電與低壓 GND 只隔 0.127mm**：P1 AC 端子、U2 IRM-02 AC 腳、繼電器 COM 腳，上下兩層 GND 鋪銅都只退 0.127mm。
   要求：IEC 60664-1（230V、OVC II、汙染等級 2）加強絕緣爬電 5.0mm／間隙 3.0mm；G5Q 繼電器自己設計值 6.4mm；Mean Well 安裝手冊要求 IRM 四周 10mm。差 40 倍以上。
2. **交流側完全沒有保護**：IRM-02 內建 T1A 保險絲只保護它自己；AC_L 經 DO_COM 供風扇的整條迴路沒有保險絲，只靠上游 16A 斷路器，遠大於走線、端子、繼電器（5A@250V）。要加慢斷保險絲。
3. **繼電器負載能力**：G5Q-1 在 250VAC 只有 5A（NO）／3A（NC，DO_3_NC、DO_4_NC 有用到），沒有馬達額定；風扇啟動湧入 5–10 倍。多段速若兩檔同時吸合會短接繞組，需韌體或硬體互鎖。
4. **12V 電源預算**：IRM-02-12 額定 167mA；4 顆繼電器全吸 133mA + 3.3V 端約 40mA ≈ 173mA，已超額（110% 起 hiccup 重啟）。若同時最多吸 1–2 顆則 OK，需確認韌體行為。

## 🟠 中
5. **LDO 輸出電容**：LM1117 規格要求 10µF 鉭電容（ESR 0.3–22Ω），板上是 MLCC，可能振盪；AMS1117 也是以 22µF 鉭電容保證穩定。
6. **LDO 散熱**：12V→3.3V 壓差 8.7V；U4 散熱銅箔只有 14.9mm²（0.023 in²），熱阻約 136°C/W，平均 40mA 約溫升 50°C；Zigbee 高功率發射時更高。建議加大銅箔或改 buck。
7. **Zigbee 模組接法**：ZS3L 的 UART（TXD/RXD）沒接到 STM32，TXD 腳拿去接 NET_LED；兩顆晶片只靠 4 進 4 出 GPIO 溝通，需要 Tuya 客製韌體，通用 MCU 串口方案無法用。要跟 原設計方／Tuya 確認韌體方案。
8. **EPA09-4D（433MHz 遙控接收）查無規格書**：電壓能否 3.3V、編碼、輸出型態、天線都未證實，要跟供應商要資料。
9. **12V 過壓時**：IRM-02 OVP 12.6–16.2V，AMS1117 絕對最大 15V，故障時可能燒 LDO（LM1117 可到 20V，較安全）。
10. **右下 Ø3.2 鍍通孔距 AC 走線 1.77mm**，若用金屬螺絲接金屬外殼會有風險。
11. **繼電器區不同市電網路最近 0.54mm**（上層）；AC_L–AC_N 1.91mm（上）／2.50mm（下），功能絕緣建議 ≥2.5mm。

## 🟡 低
12. STM32 NRST 用 1µF＋10k 上拉，建議 100nF、可省 10k。BOOT0 建議留測試點方便燒錄。VDDA 沒有獨立 1µF＋10nF。VBAT 接法原理圖看不清，需確認接 3.3V。
13. GND 鋪銅離板邊 0.26mm（JLC 一般要求 ≥0.3mm）；絲印超出板框。
14. BOM V1.0 過時（缺 R9–R12、P2）；C6/C7 標 10µF/50V 0603 實際無此料（改 25V）。

## ✅ 核對無誤
- U4 腳位（中腳＋散熱片 3.3V、兩端 12V/GND），可換 AMS1117。
- D1–D4 跨在繼電器線圈，Q1–Q4 源極接地；Si2302 在 3.3V 驅動 33mA 線圈足夠；1N4148 續流足夠。
- 繼電器 COM/NO 對到 P3；市電走線 2.0–2.3mm 寬，夠風扇電流。
- ZS3L 天線下方約 8mm 無銅；JLC Gerber 審核無紅黃；KiCad DRC 只有重建造成的假警報。

## 建議順序
1. 請 原設計方 改版：市電區鋪銅退 ≥6mm 或開槽、加保險絲（AC 入口＋DO_COM）、LDO 電容改鉭或改 buck、確認 ZS3L 韌體與 UART。
2. 確認風扇規格（電流、湧入、是否用 NC）與繼電器同時吸合數。
3. 要 EPA09-4D 規格書。
4. 若只為驗功能可先做 5 片樣板（PCB $5.2），測試一律用隔離變壓器、不交客戶使用。

## 來源
Mean Well IRM-02 https://www.meanwell.com/Upload/PDF/IRM-02/IRM-02-SPEC.PDF ・安裝手冊 https://www.meanwell.com/Upload/PDF/PCB_EN.pdf
Omron G5Q https://omronfs.omron.com/en_US/ecb/products/pdf/en-g5q.pdf
Tuya ZS3L https://developer.tuya.com/en/docs/iot/zs3l?id=K97r37j19f496
TI LM1117 https://www.ti.com/lit/ds/symlink/lm1117.pdf ・AMS1117 http://www.advanced-monolithic.com/pdf/ds1117.pdf
ST AN2586 https://www.st.com/resource/en/application_note/an2586-getting-started-with-stm32f10xxx-hardware-development-stmicroelectronics.pdf
IEC 60664-1 表格（TI SLUP421）https://www.ti.com/lit/pdf/SLUP421

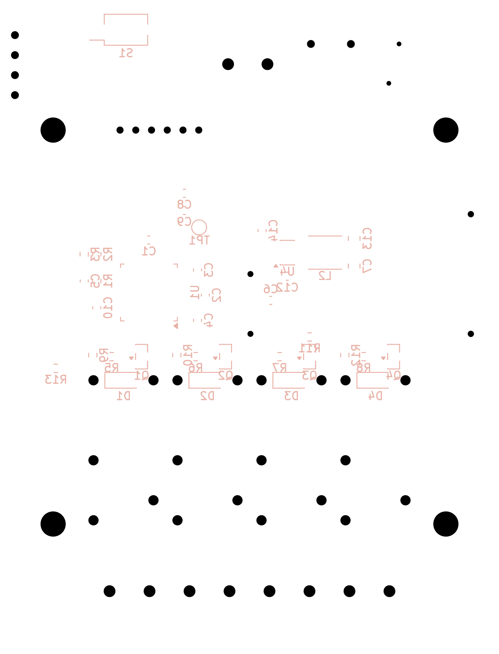
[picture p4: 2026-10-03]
docs/verification/diff/after/layers_hardware_WO30109_FreshAir_WO30109_FreshAir.kicad_pcb/preview_pspkkr-B_Silkscreen.png

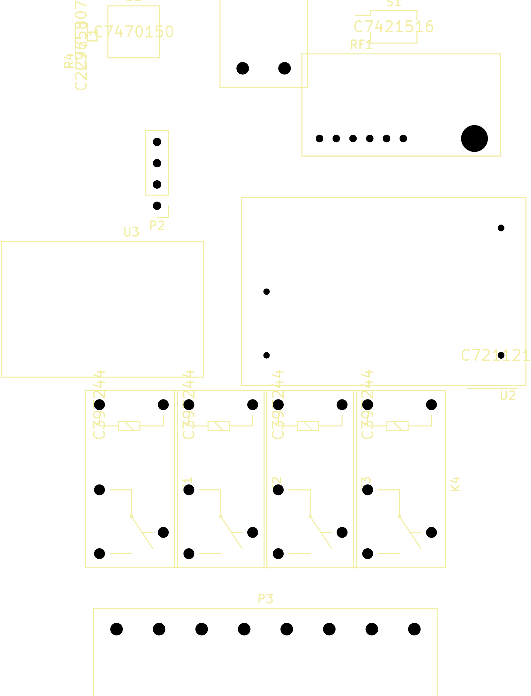
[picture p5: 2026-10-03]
docs/verification/diff/before/layers_hardware_WO30109_FreshAir_WO30109_FreshAir.kicad_pcb/preview_squ7h6-F_Silkscreen.png

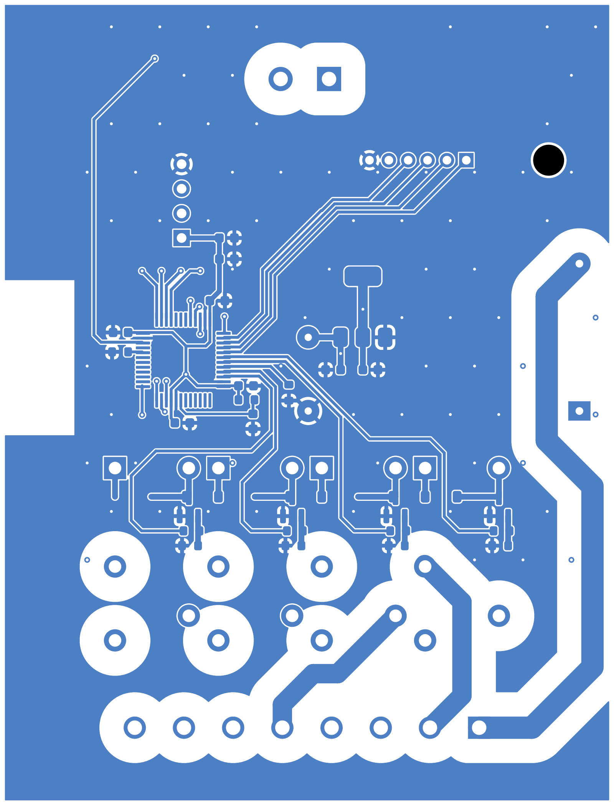
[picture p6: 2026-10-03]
docs/verification/diff/before/layers_hardware_WO30109_FreshAir_WO30109_FreshAir.kicad_pcb/preview_squ7h6-B_Cu.png

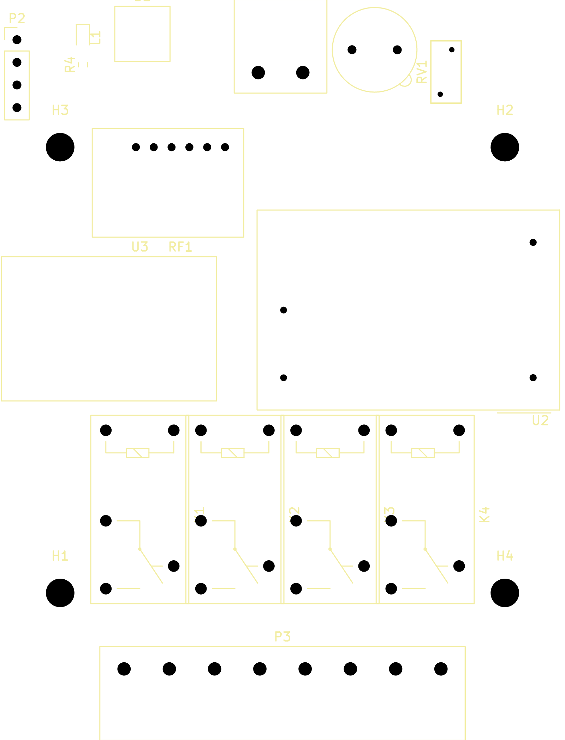
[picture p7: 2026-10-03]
docs/verification/diff/after/layers_hardware_WO30109_FreshAir_WO30109_FreshAir.kicad_pcb/preview_pspkkr-F_Silkscreen.png

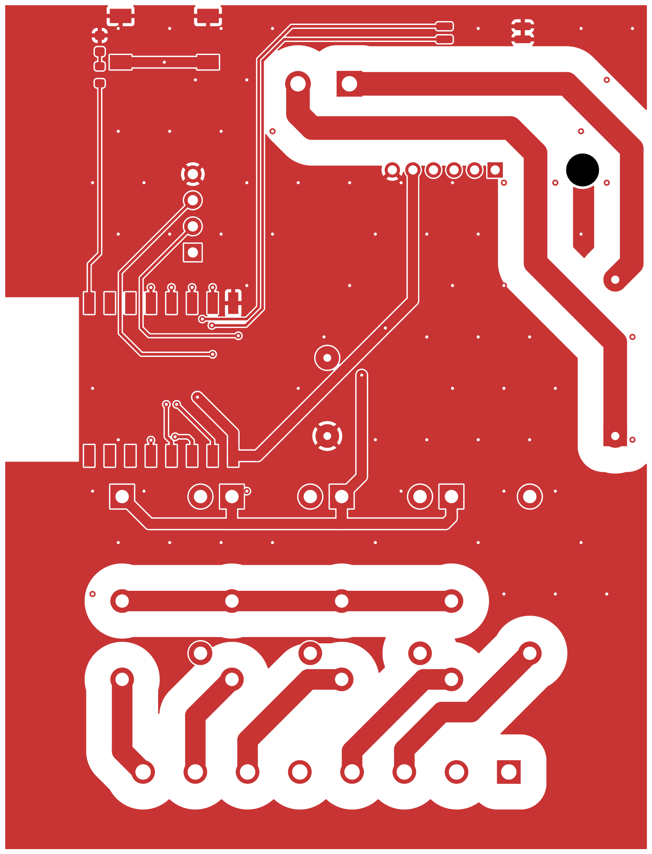
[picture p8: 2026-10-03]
docs/verification/diff/before/layers_hardware_WO30109_FreshAir_WO30109_FreshAir.kicad_pcb/preview_squ7h6-F_Cu.png

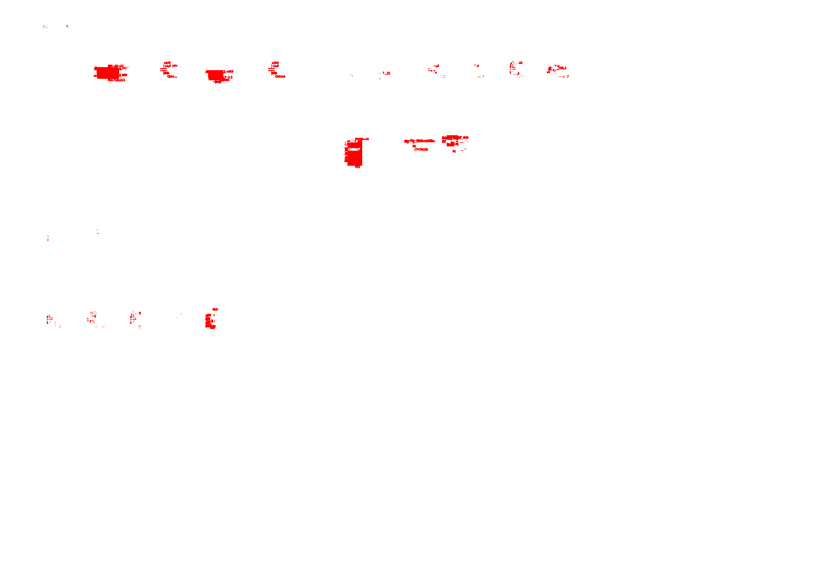
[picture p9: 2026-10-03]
docs/verification/diff/diff/hardware_WO30109_FreshAir_WO30109_FreshAir.kicad_sch-before.png

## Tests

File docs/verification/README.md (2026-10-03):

# V2.0 設計驗證報告

對象：`v2.0` 之後的 `main`（加上 GND 縫合過孔與 3D 模型）。日期 2026-10-02。
工具：KiCad 10.0.6（kicad-cli）、ngspice 42、kicad-happy 分析器（schematic / pcb / emc / spice / thermal）、kicadiff、OCP（OpenCASCADE）。

## 總表

| # | 驗證項目 | 工具 | 結果 | 判定 |
|---|---|---|---|---|
| 1 | 原理圖電氣規則（ERC） | kicad-cli | 0 個錯誤 | ✅ |
| 2 | 佈線規則（DRC）＋市電安規自訂規則 | kicad-cli＋`.kicad_dru` | 0 錯誤、0 未連線 | ✅ |
| 3 | 原理圖與 PCB 一致（parity） | kicad-cli | 0 不一致 | ✅ |
| 4 | SPICE：自動辨識子電路 | kicad-happy spice＋ngspice | 8 項全過 | ✅ |
| 5 | SPICE：繼電器驅動關斷尖峰 | ngspice（`sim/relay_driver.cir`） | 12.8V（耐壓 20V） | ✅ |
| 6 | SPICE：藍光 LED 電流 | ngspice（`sim/led.cir`） | 3.8–7.1mA | ✅ |
| 7 | PCB 計算器：走線／過孔載流 | IPC-2221（與 KiCad 計算器同公式） | 市電線餘量≈0（見下） | ⚠️ |
| 8 | PCB 計算器：分壓、時間常數 | 手算＋SPICE | 符合設計 | ✅ |
| 9 | 熱分析 | 規格書功耗＋降額曲線 | 最壞 2.6W，無需散熱片 | ✅ |
| 10 | EMC 預檢（CISPR 32 Class B） | kicad-happy emc | 風險分數 49/100（多為刻意設計） | ⚠️ |
| 11 | 3D／STEP 外形 | kicad-cli＋OCP | 正面高 16.9mm、背面 4.3mm | ✅ |
| 12 | 版本差異 V1.3 → V2.0 | kicadiff | 新增 15、變更 17 顆 | — |
| 13 | 一鍵產出（Jobset） | KiCad Jobset | 8/8 工作成功 | ✅ |

```mermaid
flowchart LR
    SCH["原理圖"] --> ERC["ERC ✅"]
    SCH --> SPICE["SPICE ✅<br/>8 子電路＋繼電器＋LED"]
    PCB["PCB"] --> DRC["DRC＋安規 ✅"]
    PCB --> CALC["PCB 計算器 ⚠️<br/>市電線餘量≈0"]
    PCB --> EMC["EMC 預檢 ⚠️"]
    PCB --> THERM["熱分析 ✅"]
    PCB --> STEP["3D／STEP ✅"]
    SCH & PCB --> PAR["parity ✅"]
    SCH & PCB --> DIFF["kicadiff V1.3→V2.0"]
    ERC & DRC & PAR --> JOB["Jobset／CI ✅"]
```

---

## 1–3. ERC／DRC／parity

```bash
kicad-cli sch erc --severity-error --exit-code-violations hardware/WO30109_FreshAir/WO30109_FreshAir.kicad_sch
kicad-cli pcb drc --schematic-parity --severity-error --exit-code-violations hardware/WO30109_FreshAir/WO30109_FreshAir.kicad_pcb
```

兩者結束碼皆為 0。DRC 包含 `.kicad_dru` 的 5 條安規規則：市電↔低壓 6.4mm、市電網路間 1.5mm、板邊 0.5mm、固定孔↔市電 2.3mm。剩下的只有絲印重疊類警告（不影響生產）。

> 注意：`.kicad_dru` 必須和 `.kicad_pcb` 放在一起。少了它，市電↔低壓 6.4mm 的檢查就不存在（kicadiff 的暫存目錄比對就是這樣漏掉的）。MAINS 網路類別間距已統一為 1.5mm，與規則一致。

---

## 4–6. SPICE 模擬

### kicad-happy 自動辨識（8 項全過）

| 子電路 | 結果 |
|---|---|
| R1/C5 重置 RC | 截止 158.8Hz（設計 159.2Hz） |
| Q1–Q4 Si2302 | Vth 1.54V、導通 |
| 3.3V 去耦（C7/C13/C1/C2/C3） | 1MHz 阻抗 4.6mΩ |
| 12V 去耦（C6/C14） | 1MHz 阻抗 33mΩ |
| 3.3V 上電湧浪 | 0.18A，穩定於 3.3V |

### 繼電器驅動（`sim/relay_driver.cir`）

線圈參數依 Omron G5Q-1 DC12 規格書（360Ω、33.3mA）；線圈電感規格書未列，取 200mH（同級小型繼電器 100–500mH）。

| 量測 | 結果 | 規格 |
|---|---|---|
| 線圈電流 | 33.3mA | 規格書 33.3mA |
| 閘極電壓 | 3.00V（R5 1k / R9 10k 分壓） | Si2302 Vth 0.63V |
| 導通 Vds | 0.57mV | — |
| **關斷尖峰（有 D1）** | **12.76V** | Si2302 Vds max 20V（餘量 36%） |
| **關斷尖峰（拿掉 D1）** | **251V** | 會擊穿 MOS → D1–D4 不可省 |
| 續流峰值電流 | 33mA | 1N4148W 遠高於此 |
| 線圈電流衰減到 1mA | 1.3ms | 繼電器釋放時間規格 5ms |

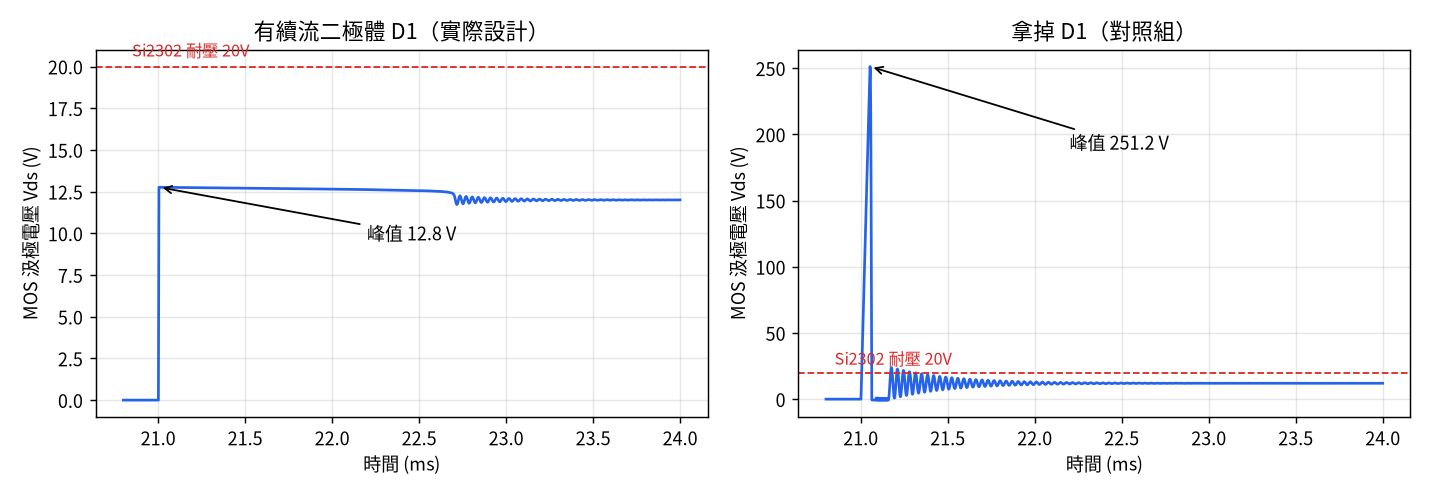
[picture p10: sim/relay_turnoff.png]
繼電器關斷波形


### 藍光 LED（`sim/led.cir`）

模型校正到規格書 Vf=3.0V@20mA，再以 Vf 偏高／偏低兩組模型包夾：**3.8–7.1mA（典型 4.9mA）**，低於 LED 20mA 與 STM32 GPIO 25mA。

---

## 7–8. PCB 計算器

公式：IPC-2221 外層 I = 0.048·ΔT^0.44·A^0.725（KiCad PCB 計算器 Track Width 頁同一公式）。外層 1oz（35µm）、ΔT=10°C。

| 網路 | 線寬 | 可承載 | 需求 | 倍數 |
|---|---|---|---|---|
| AC_L／DO_COM／各路輸出 | 1.5mm | 3.21A（ΔT20：4.35A） | 3.15A（保險絲） | **1.0** ⚠️ |
| AC_N | 1.0mm | 2.39A | 0.05A | 48 |
| +12V | 0.6mm | 1.65A | 0.15A | 11 |
| COIL1–4 | 0.6mm | 1.65A | 0.034A | 49 |
| SW（降壓） | 0.6mm | 1.65A | 0.6A | 2.8 |
| +3V3 最細段 | 0.3mm | 1.00A | 0.1A | 10 |
| 過孔 0.6/0.3 | — | 0.8A | 訊號級 | — |

**發現**：市電走線在 1oz 銅下剛好等於保險絲電流，沒有餘量。
- 風扇總電流 ≤ 3A（一般新風機 <1A）：可接受。
- 要用到繼電器 5A：下單選 **2oz 銅**（1.5mm → 5.3A），並同步換大保險絲。

| 分壓／時間常數 | 值 |
|---|---|
| MOS 閘極 R5/R9 | 3.3×10/11 = 3.00V |
| 重置 R1×C5 | 10k×100nF = 1.0ms |
| LED R4 | 100Ω → 3.8–7.1mA |
| AP63203 | 固定 3.3V 輸出，無外部分壓 |

---

## 9. 熱分析

kicad-happy 的熱分析器需要零件料號＋規格書擷取快取，本專案只有 LCSC 碼而跳過；改用規格書數據手算（`raw/thermal_manual.json`）。

| 零件 | 功耗 | 說明 |
|---|---|---|
| K1–K4 線圈 | 1.60W | 4×400mW（全吸最壞） |
| U2 IRM-02-12 | 0.62W | 輸出 1.75W＝額定 88%；降額曲線 70°C 前滿載、85°C 60% → **環境上限約 74°C** |
| 市電走線 | 0.35W | 保險絲上限 3.15A 時；實際 <1A 時 <0.04W |
| U4 AP63203 | 0.02W | V1.3 的 LM1117 是 0.35W、溫升約 +47°C |
| 其他 | <0.02W | — |
| **合計** | **≈2.6W** | 無需散熱片；密閉小盒須確認箱內 ≤60°C |

---

## 10. EMC 預檢（CISPR 32 Class B）

風險分數 49/100：error 18、warning 33、info 12。逐項判讀：

| 規則 | 數量 | 判讀 |
|---|---|---|
| GP-001 市電網路下方無參考平面 | 10 | **刻意設計**：安規要求市電下方不能有 GND |
| ES-001/002 RV1「離 P1 遠、無接地過孔」 | 2 | **誤判**：RV1 是 L-N 壓敏電阻，本就不接地、且須在保險絲之後 |
| GP-004 GND 鋪銅比例低 | 2 | 刻意設計（6.4mm 市電安全帶） |
| GP-001 低壓訊號跨越鋪銅縫隙 | 15 | 雙層板走線切割鋪銅；訊號皆為慢速 GPIO |
| RP-001 換層缺 GND 過孔 | 21 | 已加 88 顆縫合過孔＋訊號過孔旁 3 顆；MCU 區太密，58 個訊號過孔旁沒有空位 |
| SW-001 AP63203 諧波 30–960MHz | 4 | AP63203 內建展頻（FSS ±6%，規格書 §5）；輸入電容 C14 中心距 U4 約 4mm，下一版可再靠近以縮小開關迴路 |

結論：真正的 EMC 風險集中在降壓 IC 與繼電器切換市電。**正式認證前建議做傳導／輻射預掃**；MCU 區要徹底改善需改 4 層板或重新佈局。

---

## 11. 3D／STEP

3D 等角視圖

| 正面 | 背面 |
|---|---|
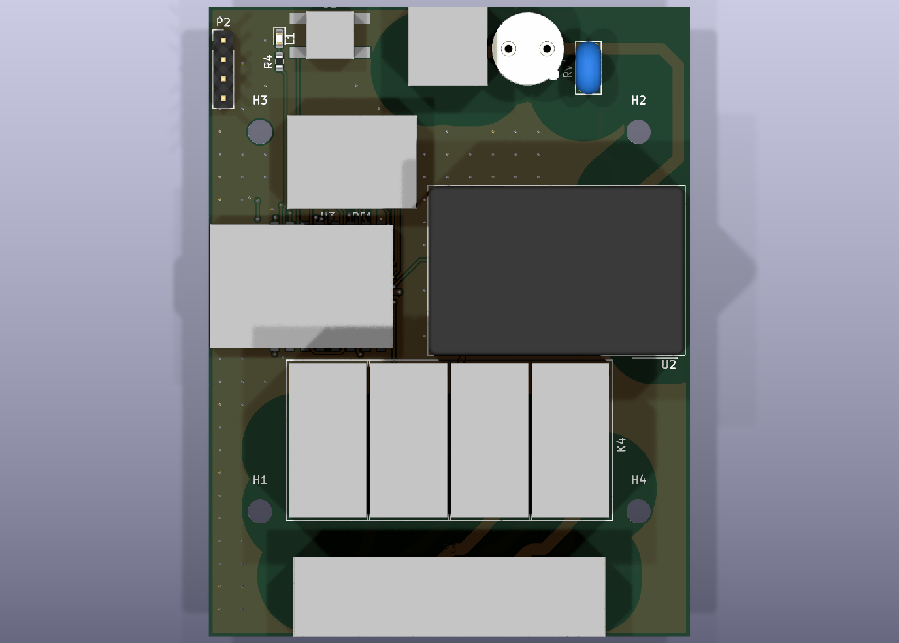
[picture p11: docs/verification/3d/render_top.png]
正面
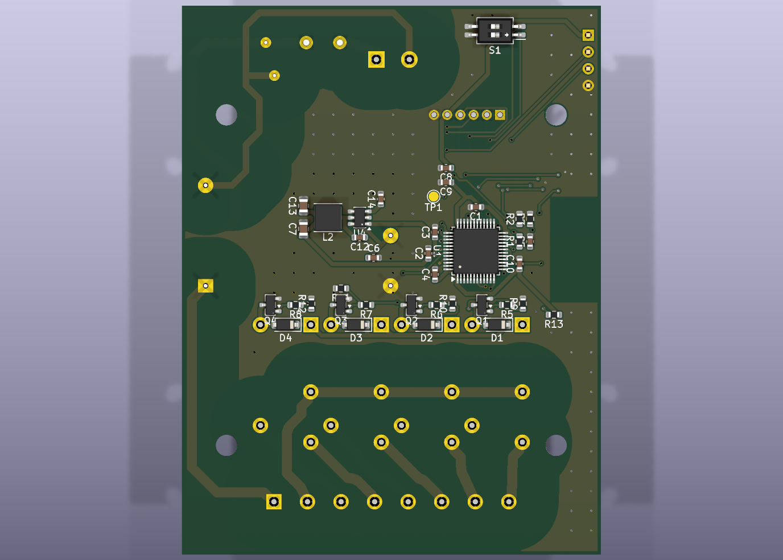
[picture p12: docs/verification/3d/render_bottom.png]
背面
|  |  |

| 項目 | 數值 |
|---|---|
| 外形 | 63.4 × 83.08mm |
| 正面最高（含板厚） | 16.9mm（G5Q 繼電器 15.3mm） |
| 背面最低 | −4.3mm（插件腳） |
| 外殼建議淨空 | 正面 ≥ 22mm（含端子插頭）、背面 ≥ 5mm |

自訂零件（G5Q、ZS3L、EPA09-4D、端子、按鍵）的 3D 模型由 `scripts/make_3d_models.py` 依規格書尺寸產生（本體方塊＋插件腳），只用於干涉與高度檢查。STEP 檔由 CI 每次產生（Artifacts → `WO30109_FreshAir.step`）。

---

## 12. 版本差異（kicadiff）

完整報告：[diff/v1.3_vs_v2.0.md](diff/v1.3_vs_v2.0.md)（原理圖新增 15、變更 17 顆；PCB 前後對照圖）。

```bash
kicadiff --markdown --output-dir docs/verification/diff -o docs/verification/diff/v1.3_vs_v2.0.md v1.3 v2.0 hardware/WO30109_FreshAir/WO30109_FreshAir.kicad_pcb
```

---

## 13. Jobset（KiCad 原生一鍵產出）

`hardware/WO30109_FreshAir/WO30109_FreshAir.kicad_jobset`：ERC → DRC → Gerber → 鑽孔 → 座標 → BOM → 原理圖 PDF → STEP，8/8 成功。ERC/DRC 只有「錯誤」等級才算失敗（`severity: 4`）。

```bash
kicad-cli jobset run --file WO30109_FreshAir.kicad_jobset WO30109_FreshAir.kicad_pro   # 在 hardware/WO30109_FreshAir/ 內執行
```

KiCad GUI：專案管理器左側檔案樹點 `.kicad_jobset` → Generate All Outputs。

---

## 待辦

| 項目 | 優先 |
|---|---|
| 負載 >3A 時改 2oz 銅＋換保險絲 | 依風扇規格 |
| 正式認證前 EMC 傳導／輻射預掃 | 高（量產前） |
| EPA09-4D 規格書（3D 高度、電壓） | 中 |
| ZS3L 實際高度（3D 模型為估計 3.3mm） | 低 |
| G5Q 線圈電感實測（SPICE 取 200mH） | 低 |

## 原始資料

`raw/`：kicad-happy 分析器 JSON（schematic、pcb、emc、spice）、`pcb_calculator.json`、`thermal_manual.json`、`3d_envelope.json`、`track_widths.json`。

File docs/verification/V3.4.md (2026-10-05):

# V3.4 驗證報告：照外殼 4-02-3 放回原板框

## 為什麼有 V3.4

使用者指定的外殼是**精鋼塑模 4-02-3**：35mm 導軌式開關盒，外形 88×72×59mm，4 個螺絲間距 50×50mm，ABS 材質。

原板 63.4×83.08mm，4 個固定孔間距 49.9×50.03mm，而且孔位置中——**原始設計就是照這個外殼做的**。V3.2／V3.3 犯了兩個錯：

1. **把板子加高到 93.08mm（V3.2）、107.2mm（V3.3）**：外殼外形才 88mm，**根本放不進去**。
2. **V3.3 的板上 NFC 線圈**：板子平躺在導軌盒底座，前蓋離板子 50mm 以上，15mm 線圈的感應距離只有 1–2cm，**手機讀不到**。

V3.4 回到原板框，在不變動市電區、繼電器區的前提下，把 DI 和 NFC 塞進去。

| 項目 | V3.3（不能用） | V3.4 |
|---|---|---|
| 板子 | 63.4 ×（左 107.2／右 83.08）L 形 | **63.4 × 83.08**（原板框） |
| DI 端子 J5 | 3.5mm 7P，在左側板邊 | **2.54mm 7P**（KF2EDGR-2.54-7P），和 P1 共用上方開窗 |
| NFC 天線 | 板上印刷線圈（讀不到） | **J6 接頭＋FPC 天線**貼在前蓋內側 |
| 燒錄 | P2 2×3 排針 | 背面 2×3 測試點（探針治具） |
| 按鍵 B1 | 6×6（擴展料） | TS-1088 3.9×3.0（**基礎料**），放在 J5 後方 |

## 1. 上緣開窗的配置與安規

上緣（y＝100）是外殼的端子開窗，P1（AC IN，市電）已經在 x 126–137：

- **J5 本體**：x 100.3–119.9（寬 19.58mm、深 8.1mm），開口朝外殼開窗。
- **J5 第 7 腳焊盤和 P1 第 2 腳焊盤**：距離 9.0mm，超過 6.4mm 加強絕緣要求。
- 3.5mm 7P（本體 25.6mm）放進來的話，第 7 腳離 P1 只剩約 4mm，所以改 2.54mm。
- **L1 狀態燈**（加上 R4）放在 J5 右邊 x≈121，從開窗看得到。
- **B1 改放在 J5 後方**：開窗被 J5 佔滿，B1 只能開蓋才按得到。原本靠按鍵的功能，NFC App 都做得到（學遙控器、恢復出廠）；燒錄改走測試點，不需要按鍵進下載模式。

## 2. NFC 天線（FPC，貼前蓋內側）

- **J6**：JST SH 1.0mm 2P 直立式接頭（BM02B-SRSS-TB，C160388），放在 J5 後方。
- **FPC 天線**：13.56MHz 軟性天線貼在前蓋凸起部位的內側，用 SH 2P 線材接回 J6。手機貼前蓋就能讀。
- **C22／C24**：調諧電容，預設**不上件**，依天線電感選值（ST25DV04KC 內建 28.5pF）：

| 天線電感 | 需外加 | C22 焊（E12） | 諧振 |
|---|---|---|---|
| 1.0 µH | 109.3 pF | 100 pF | 14.04 MHz |
| 1.5 µH | 63.3 pF | 68 pF | 13.23 MHz |
| 2.0 µH | 40.4 pF | 39 pF | 13.70 MHz |
| 2.5 µH | 26.6 pF | 27 pF | 13.51 MHz |
| 3.0 µH | 17.4 pF | 18 pF | 13.48 MHz |
| 3.5 µH | 10.9 pF | 10 pF | 13.71 MHz |
| 4.0 µH | 5.9 pF | 6.8 pF | 13.39 MHz |
| 4.5 µH | 2.1 pF | 3.3 pF | 13.30 MHz |
| 4.83 µH | ≈0 | 不上件 | 13.57 MHz |

- 天線本身若標示「適用 ST25DV」或電感約 4.8µH，就不需要外加電容。
- 建議採購電感 2–3µH 的 FPC 天線（尺寸大約 25×15mm 以內，前蓋凸起部位放得下），C22 只要焊一顆小電容。
- 打樣後用 VNA 量 J6 兩腳的諧振，或比較手機的讀取距離微調。

## 3. 佈局

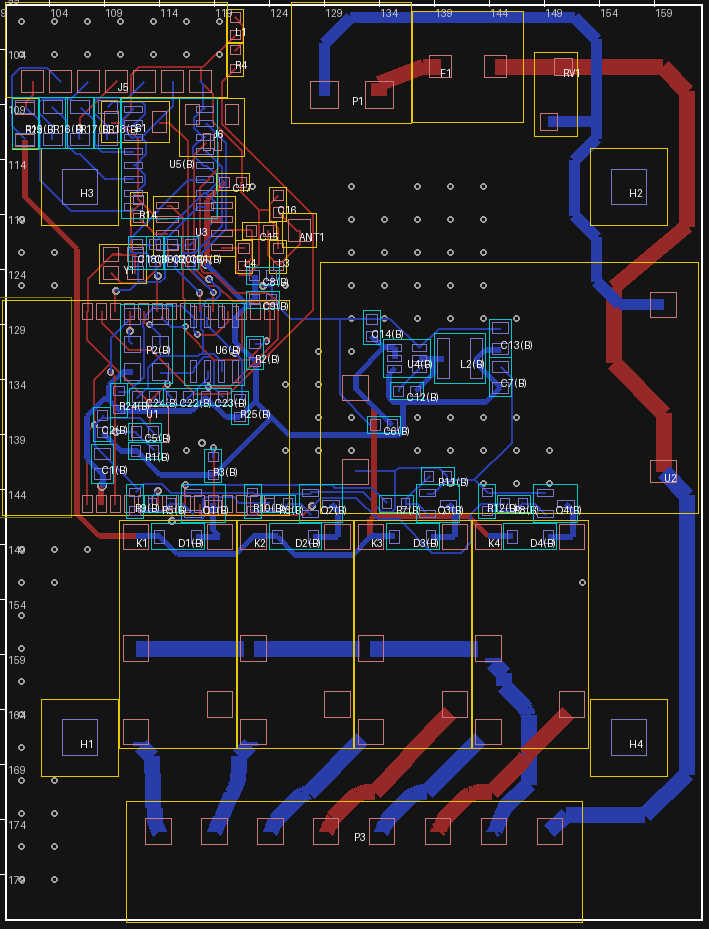
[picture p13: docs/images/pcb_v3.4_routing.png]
V3.4 佈局


- **正面左上**：J5（開口朝開窗）、L1／R4（J5 右邊，開窗看得到）；J5 後方依序是 R23、B1、J6。
- **背面左上**：R15–R18（J5 正下方）、U5（U3 正下方）。J5 焊腳排與上緣之間的口袋留空，給 DI 走線用。
- **背面、ESP32 下方**：P2 燒錄測試點、U6（NFC 晶片）、C22／C24（調諧，不上件）、C23（去耦）、R24／R25（I2C 上拉）、C18–C21（DI 濾波，緊鄰 ESP32 上排）。
- **佈線**：市電與繼電器區照 V3.1 保留（鎖定），其他低壓走線全部交給 Freerouting 重佈（和 V3.0 同一套流程：`scripts/build_v34.sh`）。

擺件調整了兩次，紀錄在 `scripts/upgrade_v34_pcb.py` 的註解裡：
1. **C18–C21 原本放在 U5 右邊**：剛好擋住左上角往下接 ESP32 唯一的背面通道（x 119–122），4 組 Freerouting 參數都留下 NFC_SCL、DI_3 佈不通。移到 ESP32 上排正下方後解決；電容貼近 GPIO 輸入，濾波效果也比較好。
2. **U6 原本放在 J5 後方的口袋**：口袋只有右端能出入，U6 左側的天線與 I2C 訊號繞不出去。移到 ESP32 下方後，第一輪 Freerouting 就全部佈通。

## 4. 驗證

```text
$ kicad-cli sch erc --severity-error --exit-code-violations …   → Found 0 violations（exit 0）
$ kicad-cli pcb drc --schematic-parity --severity-error --exit-code-violations …
Found 0 violations / Found 0 unconnected items / Found 0 schematic parity issues（exit 0）
板框 63.40 × 83.08mm；固定孔 H1–H4 位置與 V3.1 相同（間距 49.9 × 50.03mm）
J5 焊盤邊 ↔ 最近市電焊盤邊（P1 Pin2）：9.08mm（要求 ≥6.4mm）
$ python3 scripts/test_make_jlc_files.py → OK；make_jlc_files.py --check → exit 0
```

- 3 個新料號已加入 JLC 封裝快取（C577599、C720477、C160388）。
- **J6 照公開規則表會是 0°**，比對 JLC 實際封裝後是 **180°**，已自動改正。沒有 V3.0.3 的 CPL 驗證，這顆會被貼反。
- **B1 改用 TS-1088 後角度可以驗證**。剩下 RV1、U2 兩顆通孔件無法自動驗證（插反裝不進去）。
- **低壓走線全部重佈**，433 匹配網路（L3／L4／C15／C16）的走線長度會和 V3.1 略有不同，打樣後實測時一併確認。

### 這次修掉的工具問題
- `mains_router.board_height()`：原本用 `GetBoardEdgesBoundingBox()`，會把板邊線寬 0.05mm 算進去，格點因此偏 0.05mm，「離板邊 0.5mm」的遮罩少擋一格，A* 補的線會貼到板邊 0.48mm。改成用板框線段的端點計算。

## 5. JLC 網頁 PCBA 報價（2026-10-05，未下單）

- JLC 判讀板子為 2 層、83.08×63.4mm。
- BOM 31 種全部比對成功。
- 3D 檢視器裡 U6（背面）第 1 腳和絲印對齊；C22／C24 照設計留空。
- 規格和之前相同：無鉛 HASL、Standard、雙面、Confirm Parts Placement。

| 數量 | PCB | 零件 | 上料費 | 手工組裝 | 總價 | 每片 | 和 V3.3 比 |
|---|---|---|---|---|---|---|---|
| 5 | 5.20 | 87.38 | 41.85 | 2.76 | **228.73** | 45.75 | −0.12 |
| 10 | 6.40 | 155.65 | 41.85 | 5.48 | **302.38** | 30.24 | +0.60 |
| 30 | 23.60 | 428.87 | 41.85 | 16.37 | **617.96** | 20.60 | +15.23 |

- **板費變便宜**：板子回到 100mm 以下（5 片 $9.10 → $5.20）。
- **零件與手工組裝費變高**：J5 這次由 JLC 代焊（KF2EDGR-2.54-7P 端子；V3.3 的 J5 是自己手焊、沒算進去），J6 也是新料。
- **上料費持平**：B1 換成基礎料、C22 不上件，抵掉 J5、J6 兩種新擴展料。
- **另外要買**：FPC 天線（JLC 沒有）。

## 6. 韌體

V3.4 的 GPIO 和 V3.3 完全相同：DI_1–4＝IO3／IO15／IO22／IO21，NFC I2C＝IO20／IO19。所以韌體（PR #11）的 menuconfig「板子版本」選 V3.3 就適用 V3.4。

## 7. 待辦

- 採購 FPC 天線、確認電感，決定 C22 的值。
- 外殼：確認前蓋凸起部位的內側空間可以貼天線，以及 J5 插頭從開窗插拔時不會卡到外殼。
- 打樣後實測：NFC 讀取距離、J5 的 2.54mm 插頭線徑（最大 0.5mm²）是否夠用。

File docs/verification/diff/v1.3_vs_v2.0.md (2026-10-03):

## `hardware/WO30109_FreshAir/WO30109_FreshAir.kicad_sch` (sch)

| Before (ef9fa8c) | After (0b9c355) |
| --- | --- |
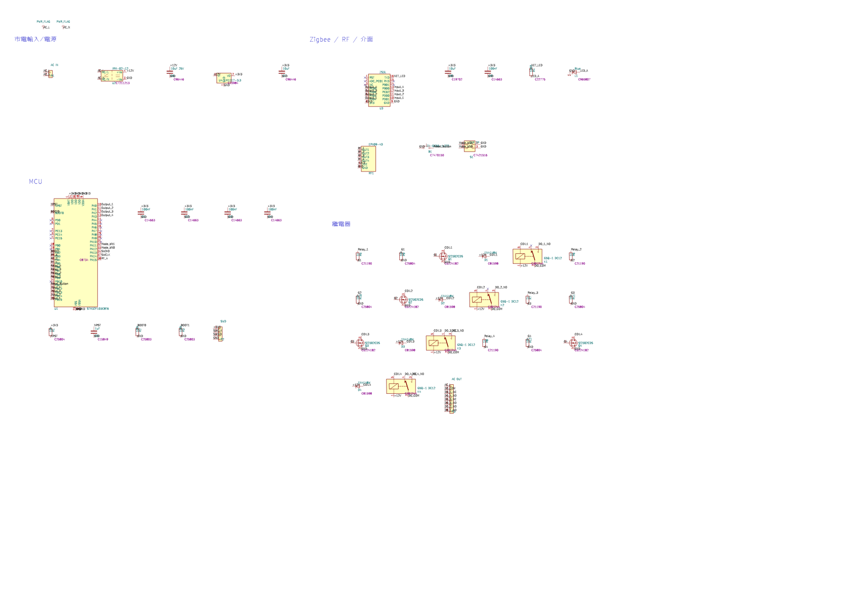
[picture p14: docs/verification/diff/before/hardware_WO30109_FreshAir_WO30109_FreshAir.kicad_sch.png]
Before
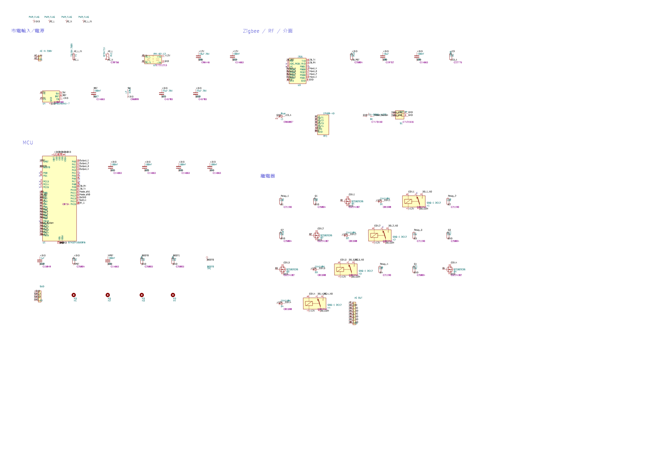
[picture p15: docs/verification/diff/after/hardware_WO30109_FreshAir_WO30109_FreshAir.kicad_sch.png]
After
|  |  |

`+15` `-0` `~17` `=29`

### Added (15)
- `#FLG03/1` `PWR_FLAG` `power:PWR_FLAG` at `(59.69,20.32)`
- `#FLG04/1` `PWR_FLAG` `power:PWR_FLAG` at `(74.93,20.32)`
- `C10/1` `1uF` `Device:C` at `(35.56,233.68)`
- `C12/1` `100nF` `Device:C` at `(83.82,83.82)`
- `C13/1` `22uF 25V` `Device:C` at `(175.26,83.82)`
- `C14/1` `100nF` `Device:C` at `(208.28,50.80)`
- `F1/1` `T3.15A 250V` `Device:Fuse` at `(66.04,50.80)`
- `H1/1` `M3` `Mechanical:MountingHole` at `(66.04,264.16)`
- `H2/1` `M3` `Mechanical:MountingHole` at `(96.52,264.16)`
- `H3/1` `M3` `Mechanical:MountingHole` at `(127.00,264.16)`
- `H4/1` `M3` `Mechanical:MountingHole` at `(154.94,264.16)`
- `L2/1` `3.9uH` `Device:L` at `(114.30,83.82)`
- `R13/1` `10k` `Device:R` at `(314.96,50.80)`
- `RV1/1` `07D471K` `Device:Varistor` at `(96.52,50.80)`
- `TP1/1` `BOOT0` `Connector:TestPoint` at `(185.42,233.68)`

### Changed (17)
- `B1/1` — pos: `299.72,104.14` → `330.20,104.14`
- `C5/1` — value: `1uF` → `100nF`, pos: `66.04,233.68` → `96.52,233.68`
- `C6/1` — pos: `119.38,50.80` → `177.80,50.80`
- `C7/1` — value: `10uF` → `22uF 25V`, pos: `198.12,50.80` → `144.78,83.82`
- `C8/1` — pos: `314.96,50.80` → `342.90,50.80`
- `C9/1` — pos: `342.90,50.80` → `373.38,50.80`
- `L1/1` — pos: `403.86,50.80` → `251.46,104.14`
- `P1/1` — value: `AC IN` → `AC IN 230V`
- `P2/1` — pos: `154.94,233.68` → `35.56,264.16`
- `R1/1` — pos: `35.56,233.68` → `66.04,233.68`
- `R2/1` — pos: `96.52,233.68` → `127.00,233.68`
- `R3/1` — pos: `127.00,233.68` → `154.94,233.68`
- `R4/1` — pos: `373.38,50.80` → `403.86,50.80`
- `RF1/1` — pos: `259.08,111.76` → `289.56,111.76`
- `S1/1` — pos: `330.20,104.14` → `358.14,104.14`
- `U2/1` — pos: `78.74,53.34` → `137.16,53.34`
- `U4/1` — value: `LM1117-3.3` → `AP63203WU-7`, libId: `Regulator_Linear:AMS1117-3.3` → `Regulator_Switching:AP63203WU`, pos: `157.48,53.34` → `45.72,86.36`

## `hardware/WO30109_FreshAir/WO30109_FreshAir.kicad_pcb` (pcb)

| Before (ef9fa8c) | After (0b9c355) |
| --- | --- |
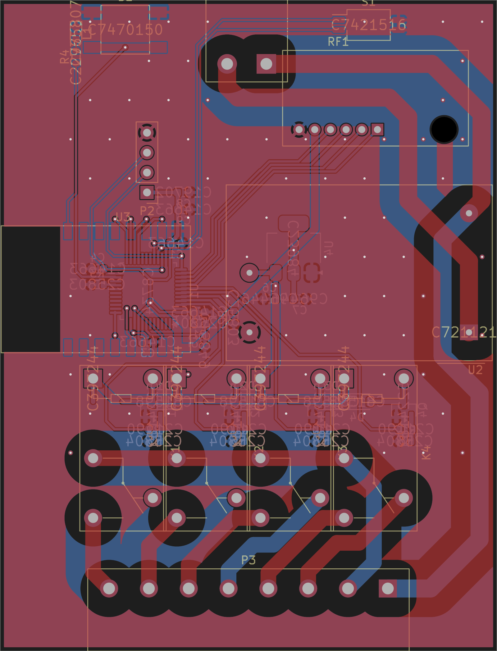
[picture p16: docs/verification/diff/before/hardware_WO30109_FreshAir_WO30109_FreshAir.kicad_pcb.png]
Before
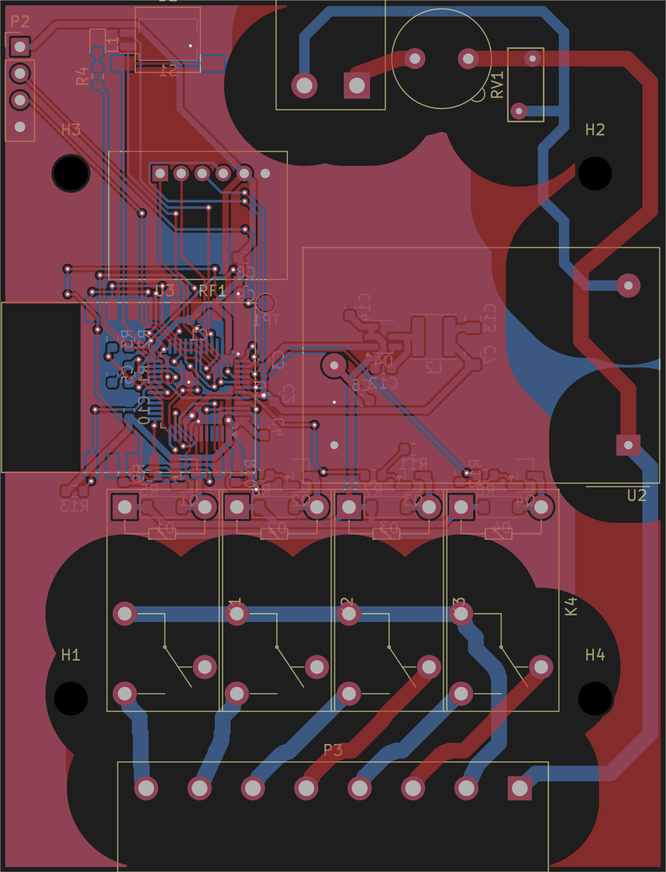
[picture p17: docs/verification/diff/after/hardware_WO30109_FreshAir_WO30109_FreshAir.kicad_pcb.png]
After
|  |  |

`+13` `-0` `~40` `=4`

### Added (13)
- `C10` `1uF` `Capacitor_SMD:C_0603_1608Metric` at `(112.30,139.08)`
- `C12` `100nF` `Capacitor_SMD:C_0603_1608Metric` at `(136.50,135.08)`
- `C13` `22uF 25V` `Capacitor_SMD:C_0805_2012Metric` at `(145.00,130.28)`
- `C14` `100nF` `Capacitor_SMD:C_0603_1608Metric` at `(133.30,129.28)`
- `F1` `T3.15A 250V` `Fuse:Fuseholder_TR5_Littelfuse_No560_No460` at `(139.50,105.58)`
- `H1` `M3` `MountingHole:MountingHole_3.2mm_M3` at `(106.75,166.55)`
- `H2` `M3` `MountingHole:MountingHole_3.2mm_M3` at `(156.65,116.52)`
- `H3` `M3` `MountingHole:MountingHole_3.2mm_M3` at `(106.75,116.52)`
- `H4` `M3` `MountingHole:MountingHole_3.2mm_M3` at `(156.65,166.55)`
- `L2` `3.9uH` `Inductor_SMD:L_Sunlord_SWPA4030S` at `(141.30,132.08)`
- `R13` `10k` `Resistor_SMD:R_0603_1608Metric` at `(107.10,146.78)`
- `RV1` `07D471K` `Varistor:RV_Disc_D7mm_W3.4mm_P5mm` at `(150.70,105.58)`
- `TP1` `BOOT0` `TestPoint:TestPoint_Pad_D1.5mm` at `(125.30,128.88)`

### Changed (40)
- `C1` — pos: `122.45,131.03` → `118.90,130.48`
- `C2` — pos: `125.40,139.80` → `126.10,137.48`, angle: `` → `90`
- `C3` — pos: `118.83,143.63` → `125.10,134.28`, angle: `` → `90`
- `C4` — pos: `112.45,134.30` → `125.10,140.68`, angle: `180` → `90`
- `C5` — value: `1uF` → `100nF`, pos: `126.13,143.48` → `110.70,135.68`, angle: `-90` → `90`
- `C6` — pos: `134.39,138.15` → `134.40,138.15`
- `C7` — value: `10uF` → `22uF 25V`, libId: `Capacitor_SMD:C_0603_1608Metric` → `Capacitor_SMD:C_0805_2012Metric`, pos: `138.25,138.15` → `145.00,133.78`, angle: `` → `90`
- `C8` — pos: `123.42,124.55` → `123.42,124.56`
- `D1` — pos: `120.90,151.25` → `115.69,148.29`, angle: `180` → ``
- `D2` — pos: `131.57,151.25` → `126.36,148.29`, angle: `180` → ``
- `D3` — pos: `142.25,151.25` → `137.03,148.29`, angle: `180` → ``
- `D4` — pos: `145.55,151.25` → `147.71,148.29`
- `K1` — libId: `Relay_THT:Relay_SPDT_Omron-G5Q-1` → `WOOW:Relay_SPDT_Omron-G5Q-1_Tight`
- `K2` — libId: `Relay_THT:Relay_SPDT_Omron-G5Q-1` → `WOOW:Relay_SPDT_Omron-G5Q-1_Tight`
- `K3` — libId: `Relay_THT:Relay_SPDT_Omron-G5Q-1` → `WOOW:Relay_SPDT_Omron-G5Q-1_Tight`
- `K4` — libId: `Relay_THT:Relay_SPDT_Omron-G5Q-1` → `WOOW:Relay_SPDT_Omron-G5Q-1_Tight`
- `L1` — pos: `109.70,104.24` → `109.30,104.24`
- `P1` — value: `AC IN` → `AC IN 230V`, pos: `131.47,108.15` → `131.48,108.15`
- `P2` — pos: `118.75,124.55` → `101.90,104.46`, angle: `180` → ``
- `P3` — pos: `131.69,175.08` → `131.70,175.08`
- `Q1` — pos: `119.50,152.31` → `117.99,145.29`, angle: `90` → ``
- `Q2` — pos: `130.17,152.31` → `128.66,145.29`, angle: `90` → ``
- `Q3` — pos: `140.84,152.31` → `139.33,145.29`, angle: `90` → ``
- `Q4` — pos: `151.52,152.31` → `150.01,145.29`, angle: `90` → ``
- `R1` — pos: `125.45,141.25` → `112.30,135.68`, angle: `` → `90`
- `R2` — pos: `129.82,140.50` → `112.30,132.28`, angle: `-90` → `90`
- `R3` — pos: `112.40,136.30` → `110.70,132.28`, angle: `180` → `90`
- `R4` — pos: `109.70,107.27` → `109.30,107.28`
- `R5` — pos: `119.77,154.77` → `114.19,145.29`
- `R6` — pos: `130.45,154.77` → `124.86,145.29`
- `R7` — pos: `141.12,154.77` → `135.53,145.29`
- `R8` — pos: `151.79,154.77` → `146.21,145.29`
- `R9` — pos: `119.62,156.30` → `111.79,145.09`, angle: `180` → `90`
- `R10` — pos: `130.30,156.30` → `122.46,145.09`, angle: `180` → `90`
- `R11` — pos: `140.97,156.30` → `139.33,142.79`, angle: `180` → ``
- `R12` — pos: `151.64,156.30` → `143.81,145.09`, angle: `180` → `90`
- `RF1` — pos: `143.15,116.53` → `120.25,116.52`, angle: `` → `180`
- `S1` — pos: `147.02,103.19` → `116.00,103.78`
- `U3` — pos: `115.67,136.90` → `115.68,136.91`
- `U4` — value: `LM1117-3.3` → `AP63203WU-7`, libId: `Package_TO_SOT_SMD:SOT-223-3_TabPin2` → `Package_TO_SOT_SMD:TSOT-23-6`, pos: `137.47,131.65` → `136.50,132.08`, angle: `90` → ``

### Nets (+7 -7 ~16)
- `+` `/AC_L_IN`
- `+` `/BST`
- `+` `/LED`
- `+` `/SW`
- `+` `/ZB_RST`
- `+` `/ZB_RX`
- `+` `/ZB_TX`
- `-` `/NET_LED`
- `-` `unconnected-(U1-PA10-Pad31)`
- `-` `unconnected-(U1-PA9-Pad30)`
- `-` `unconnected-(U1-PB0-Pad18)`
- `-` `unconnected-(U1-PB1-Pad19)`
- `-` `unconnected-(U3-RST-Pad1)`
- `-` `unconnected-(U3-RXD-Pad15)`
- `~` `P1.1` — `/AC_L` → `/AC_L_IN`
- `~` `R4.1` — `/NET_LED` → `/LED`
- `~` `U1.18` — `unconnected-(U1-PB0-Pad18)` → `/LED`
- `~` `U1.19` — `unconnected-(U1-PB1-Pad19)` → `/ZB_RST`
- `~` `U1.30` — `unconnected-(U1-PA9-Pad30)` → `/ZB_RX`
- `~` `U1.31` — `unconnected-(U1-PA10-Pad31)` → `/ZB_TX`
- `~` `U2.1` — `/AC_N` → `/AC_L`
- `~` `U2.2` — `/AC_L` → `/AC_N`
- `~` `U3.1` — `unconnected-(U3-RST-Pad1)` → `/ZB_RST`
- `~` `U3.15` — `unconnected-(U3-RXD-Pad15)` → `/ZB_RX`
- `~` `U3.16` — `/NET_LED` → `/ZB_TX`
- `~` `U4.1` — `/GND` → `/+3V3`
- `~` `U4.2` — `/+3V3` → `/+12V`
- `~` `U4.4` — `(unconnected)` → `/GND`
- `~` `U4.5` — `(unconnected)` → `/SW`
- `~` `U4.6` — `(unconnected)` → `/BST`

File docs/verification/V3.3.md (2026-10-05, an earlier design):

# V3.3 驗證報告：NFC 設定介面

V3.3 在 V3.2（4 路 DI）的基礎上加了 NFC：手機 App 貼近板子，就能讀寫 DI／DO 模式、點動時間、遙控器清單等進階設定。Apple Home／Google Home 只能做開關，這些設定改由 NFC 處理，不需要 Wi-Fi 熱點，也不會讓 Matter 斷線。

- **NFC 晶片**：U6 ST25DV04KC（C3304276）。手機端走 ISO 15693（NFC Type 5），iOS Core NFC 和 Android 都支援；ESP32 經 I2C 讀同一份資料。
- **天線**：L5，板上印刷線圈（不另外買天線），14.9×14.6mm、8 圈。
- **J5 改到左側板邊**：DI 電線從左側出，左上角留給線圈。左半段上緣從 y=93.08 提高到 107.2mm。

PCB 一樣以 V3.1 為起點，用同一支腳本重建：`WO_VER=3.3 python3 scripts/upgrade_v32_pcb.py`。不跑 Freerouting，市電區、繼電器區、433 匹配區的佈線都不動。

| # | 項目 | 結果 |
|---|---|---|
| 1 | ERC | 0 錯誤、0 警告 |
| 2 | DRC（含市電安規）與原理圖一致性 | 錯誤 0、未連線 0、不一致 0；警告只有絲印類 |
| 3 | 線圈禁布區 | 只有線圈自己的背面跨線；正反兩面 GND 鋪銅取樣 0/900 |
| 4 | 線圈電感 | 1.277µH（以實際封裝銅箔計算；計算程式與矩形單匝公式解差 0.1–0.2%） |
| 5 | 諧振頻率 | 28.5pF（內建）＋75pF → 13.84MHz |
| 6 | CPL | U6 用 JLC 封裝求得唯一解 270°；`test_make_jlc_files.py` OK、`--check` exit 0 |
| 7 | V3.2 仍可重建 | 共用的佈線器與腳本改過後，V3.2 用新程式重建，DRC 依然乾淨（見 §5） |

## 1. 電路

```text
          L5 印刷線圈 1.27µH                     U6 ST25DV04KC（SO-8）
   AC0 ─┬─────(((((((((((─────┬─ AC1        2 AC0      VCC 8 ── +3V3 ─ C23 100nF
        ├── C22 75pF C0G ─────┤             3 AC1      SDA 5 ── R24 10k ↑ ── IO20（U1 第 18 腳）
        └── C24（空位，微調）─┘             4 VSS      SCL 6 ── R25 10k ↑ ── IO19（U1 第 17 腳）
                                             1 V_EH（不用）  GPO 7（不接）
```

- **ST25DV04KC 腳位**（ST 規格書 Figure 2，SO8N）：1 V_EH、2 AC0、3 AC1、4 VSS、5 SDA、6 SCL、7 GPO（開汲極）、8 VCC。
- **記憶體**：使用者 EEPROM 4Kbit（512 bytes），另有 256 bytes 的 mailbox。手機和 ESP32 之間的即時一問一答走 mailbox。
- **GPO 不接**：韌體每 50ms 用 I2C 讀一次 IT_STS_Dyn 暫存器（RF 場、mailbox 狀態）。少一條長線；50ms 的反應時間對設定介面足夠。
- **V_EH 不接**：能量擷取輸出預設關閉。
- **I2C**：上拉 10kΩ（BOM 已有的基礎料）。ST25DV 的 I2C 位址是 0x53（使用者記憶體）／0x57（系統設定）。

### 線圈與調諧（`scripts/nfc_coil.py`）

ST25DV 內建調諧電容 28.5pF。要諧振在 13.56MHz，線圈需要 4.83µH，但板上只有 15mm 見方，8 圈只做得到 1.27µH，所以並聯 C22 補足電容。這是小型 NFC 天線的標準做法。

| 外加電容 | 諧振頻率 |
|---|---|
| 68pF | 14.33MHz |
| **75pF（C22，C1681）** | **13.84MHz** |
| 82pF | 13.40MHz |

- **故意調在 13.56MHz 以上一點**：裝進塑膠外殼、手機靠近之後，諧振會往下掉幾百 kHz。
- **C24 留空位不焊**：打樣後用 VNA（或手機感應距離）實測，必要時加幾 pF 微調。
- **電感計算**：讀封裝裡的實際銅箔線段，用部分電感法計算（直線段自感＋平行段互感數值積分）。程式和矩形單匝公式解相比，22×16、40×25、10×10mm 三種尺寸差都在 0.1–0.2% 以內。
- **線圈封裝**（`WOOW:NFC_Coil_14.9x14.6mm_8T`）：
  - 線寬／間距 0.2／0.2mm，畫在正面；最內圈端點經 THT 焊盤，從背面拉到線圈外。
  - net tie（"1, 2"）：讓線圈銅箔合法連接兩個焊盤（電感在直流是短路）。
  - 禁布區（線圈外擴 0.5mm）上下兩層禁止鋪銅和過孔。走線限制放寬，是為了放線圈自己的背面跨線；別的網路由佈線器擋在外面。
  - 背面跨線由 PCB 腳本畫成真正的走線。封裝圖形不算連接，如果把跨線畫在封裝裡，內外兩個「2」號焊盤會被判成未連線。
- **75pF 的庫存**：JLC 約 3000 顆，打樣和小量沒問題；量產時可改用 68pF（C1680，庫存近 10 萬）再加 C24 微調。

## 2. ESP32 腳位重新分配

V3.3 的上排有 6 條線要進 ESP32：DI_1–4 加上 I2C 兩條。如果照 V3.2 的接法，DI 長線和 I2C 長線會在 U3（433 接收晶片）底下互相交叉，佈線器找不到路。改成照左右順序一對一接，彼此就不交叉：

| 起點（左→右） | DI_1（C18） | DI_2（C19） | DI_3（C20） | DI_4（C21） | SDA（R24） | SCL（R25） |
|---|---|---|---|---|---|---|
| U1 腳 | 26 | 23 | 20 | 19 | 18 | 17 |
| GPIO | IO3 | IO15 | IO22 | IO21 | IO20 | IO19 |

- **IO15 是 strapping 腳**：只有燒了 `EFUSE_JTAG_SEL_ENABLE` 才會在開機時讀它（用來選 JTAG 來源），出廠預設不讀。所以 DI_2 在開機時被接點拉低也不影響開機。
- 其餘 strapping 腳（GPIO4、5、8、9）都沒有用到。
- **韌體 `board.h` 要改成 V3.3 的腳位**，會在 NFC 韌體 PR 一起改。V3.2 的腳位（DI 接 IO22–IO19）只適用於 V3.2 板。

## 3. 佈局

```text
   y=75.9 ┌───────────────────────┐
          │ J5 ▶│  L5 NFC 線圈     │   ← J5 開口朝左；由下往上 +12V、IN1–4、COM、GND
  (左側   │ 7P  │  14.9×14.6mm     │
   出線)  │     └──────────────────┤
          │       C22 C24   U6     │
   y=100  │ P2   B1      U5        ├─────────┐ ← P1（AC IN）前方維持原板緣
          │  ESP32 …               │  P1 F1 RV1 …
```

- **J5**：直立貼左側板邊，開口朝左。這個封裝開口朝左時 1 腳一定在下面，所以由下往上依序是 +12V、IN1–IN4、COM、GND；背面絲印印在焊盤右邊。
- **R15–R18、R23**：放在背面、J5 本體底下（板邊和焊盤之間），分兩欄交錯，各自對齊所接的腳。R23 放在左欄最上面，讓下方 y≈100 的窄帶留給 DI 線出去接 U5。
- **L5**：x 110.5–125.4、y 76.4–91.0（KiCad 座標）。距 J5 焊盤 2mm、距板邊 0.5mm；距最近的市電銅箔（P1）超過 15mm。
- **U6、C22、C24**：正面，放在線圈正下方；AC0／AC1 在 U6 左側，靠近線圈焊盤。C23（去耦）、R24／R25（上拉）放在 U6 正背面。
- **佈線順序**：依序佈線時，結果和順序有關。以下是試出來的順序，原因都寫在腳本註解裡：
  1. U5 周邊；
  2. NFC 短線；
  3. I2C 長線（先佈外側的 SCL）；
  4. +12V（R23 在左上角，從 U2 拉過來）；
  5. DI 長線，自動試所有排列；
  6. 最後是 +3V3，一路接 U6、C23、上拉電阻，再接回 P2 和 U3。

## 4. 這次修掉的佈線器問題（`mains_router.py`）

- **禁布區沒有算線寬**：只塗禁布區多邊形的話，走線中心可以貼著邊緣，線寬就吃進禁布區 0.2mm。現在多邊形外圍再擴「半線寬＋0.05mm」。
- **只認禁止走線的禁布區**：現在禁止走線**或**禁止鋪銅的禁布區都算障礙。
- **只認矩形板框**：現在讀真實板框（L 形），板外再往內擴「板邊間距＋半線寬」。原本有一顆過孔離 L 形轉角太近。
- **KiCad 10 API 名稱**：`GetDoNotAllowZoneFills`（不是 CopperPour）、`GetBoardPolygonOutlines(ps, False)`。
- **`add_stitching.py --prune`**：同時移除 DRC 判為懸空的 GND 過孔。新走線把背面鋪銅切開後，舊的縫合過孔可能只剩一層接得到。
- **殘線清理**：範圍加上 P2 第 1 腳附近。V3.3 擺件後那裡留下一段 1.8mm 的 +3V3 殘線。

以上都只是讓佈線器「更保守」。V3.2 用新程式重建後 DRC 依然乾淨（§5）。

## 5. V3.2 用新程式重建

在獨立的 git worktree（`rev/v3.2`）裡，換上 V3.3 版的共用腳本，產生 V3.2 原理圖後重建 V3.2 PCB（`WO_VER=3.2`）：

```text
$ python3 scripts/drc_summary.py
errors: {}
warnings: {'silk_overlap': 41, 'silk_over_copper': 58, 'silk_edge_clearance': 3}
unconnected: 0  parity: 0
```

警告數量和 PR #8 的 V3.2 板完全相同。

## 6. BOM 與成本

- **新增**：U6 ST25DV04KC（擴展料，$0.94／1 片、$0.59／100 片）、C22 75pF C0G（擴展料）。
- **沿用 BOM 已有的料**：C23 100nF、R24／R25 10k。
- **不上件**：L5 是純銅箔；C24 是微調空位。
- **合計**：30 種、64 顆。比 V3.2 多 2 種擴展料，上料費多約 $3–6（每張訂單一次）。

## 7. JLC 網頁 PCBA 報價（2026-10-05，未下單）

- JLC 判讀板子為 2 層、107.2×63.4mm。
- BOM 30 種全部比對成功。
- 3D 檢視器裡 U6 第 1 腳圓點和絲印三角形對齊；C24 照設計留空。
- 規格和 V3.2 相同：無鉛 HASL、Standard、雙面、Confirm Parts Placement。

| 數量 | PCB | 零件 | 上料費 | 總價 | 每片 | 和 V3.2 比 |
|---|---|---|---|---|---|---|
| 5 | 9.10 | 84.13 | 41.85 | **228.85** | 45.77 | +11.94 |
| 10 | 13.10 | 149.50 | 41.85 | **301.78** | 30.18 | +17.97 |
| 30 | 29.00 | 411.68 | 41.85 | **602.73** | 20.09 | +28.01 |

- **PCB 費變貴最多**：板子高度 93.08 → 107.2mm。JLC 的 100mm 以下有優惠價，超過就失去優惠。
- **上料費多 $3.10**：2 種新擴展料（U6、C22）。
- **零件**：每片多約 $1。

## 8. 待辦與限制

- **韌體（另開 PR）**：
  - ST25DV I2C 驅動、設定資料格式與 mailbox 指令（給 App 開發用的規格文件）；
  - `board.h` 改成 V3.3 腳位；
  - 電腦端測試工具（USB NFC 讀卡機）。
- **打樣後實測**：
  - 諧振頻率（VNA 量 AC0–AC1，或比較手機在不同距離能不能讀到），必要時用 C24 微調；
  - iPhone／Android 在外殼外的感應距離（預估 1–2cm）；
  - 線圈靠近 ESP32 天線（約 35mm）時，會不會影響 Zigbee／Thread。
- **外殼**：
  - 板子變成 L 形，左半段高 107.2mm、右半段維持 83.08mm；
  - 線圈那一面要是塑膠，而且要貼近外殼表面，並在外殼上標 NFC 感應位置；
  - DI 電線改從左側出線。

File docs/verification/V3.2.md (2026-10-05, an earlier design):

# V3.2 驗證報告：4 路光耦 DI 輸入

V3.2 做了三件事：

- 在板子上緣**左半段（J5 那一段）**加長 10mm，放 4 路光耦隔離的數位輸入（DI）。板子變成 L 形：P1（AC IN）前方維持原本板緣。輸入可以接乾接點，也可以接 5–24VDC（NPN 或 PNP 輸出都可以）。
- 拿掉指撥開關 S1，模式改由軟體設定。
- 市電區、繼電器區的佈線完全不動。

PCB 以 V3.1 的 PCB 為起點，用 `scripts/upgrade_v32_pcb.py` 一鍵重建。新網路由格點 A* 佈線器佈線，佈線器會讓新走線和市電保持 6.5mm 間距，**不重跑 Freerouting**，所以既有走線都不會被改動。

| # | 項目 | 結果 |
|---|---|---|
| 1 | ERC | 0 |
| 2 | DRC（含市電安規 `.kicad_dru`）與原理圖一致性 | 錯誤 0、未連線 0、不一致 0；警告只有絲印類 |
| 3 | 從頭重建是否可重現 | `python3 scripts/upgrade_v32_pcb.py` 從 V3.1 開始，結果相同 |
| 4 | 433 匹配區 | 新走線全部繞開 L3／L4／C15／C16／ANT1（上下兩層都設禁佈） |
| 5 | CPL 角度 | 新料都用 JLC 封裝驗證；U5（背面 SOP-16）為 180° |
| 6 | 電源預算 | 最壞約 143mA（額定 167mA 的 86%） |

## 1. 電路

```text
J5（7P 3.5mm 插拔）           背面                        U1 ESP32-C6（上排）
 1 +12V  ← R23 1.5k ← +12V
 2 IN1 ─ R15 3.3k ─┐
 3 IN2 ─ R16 3.3k ─┤  U5 TLP290-4（交流輸入光耦 ×4）
 4 IN3 ─ R17 3.3k ─┼→ LED（反向並聯）─┐   集極 ─┬─ 10nF ─ GND
 5 IN4 ─ R18 3.3k ─┘                   │         └──────────→ IO22／IO21／IO20／IO19（內建上拉）
 6 COM ────────────────────────────────┘   射極 ─ GND
 7 GND
```

- **光耦 U5：** TLP290-4(GB)，C39031，庫存 3.5 萬。CTR 下限 100%（IF 5mA 時）；輸入與輸出之間隔離 2.5kVrms。LED 是反向並聯，**不分極性**，所以 NPN 和 PNP 輸出都能接。
- **GPIO：** DI1–DI4 接 U1 上排的 IO22／IO21／IO20／IO19（第 20–17 腳），都不是 strapping 腳。
  - U5 就在這幾腳正上方約 16mm，走線從背面直接往上。
  - 左右順序和 U5 的輸出一致，走線不會交叉。
  - 原本指撥用的 IO10／IO11（下排）空出來了。
- **不用外部上拉電阻：**
  - ESP32 內建上拉約 45kΩ，光耦只需要吸收約 73µA。
  - 10nF 電容讓時間常數約 0.45ms，在高頻時是低阻抗，這條約 5cm 的線不容易收到雜訊。
- **R23 1.5kΩ 1206：** 限制端子 +12V 的電流。
  - 端子短路時最多 8mA、0.096W，是額定 0.25W 的 38%，可以長期短路，IRM-02 也不會進保護。
  - 起初選 680Ω 2512，但板上找不到可以放的位置；也考慮過自恢復保險絲，但它的跳脫電流 150mA 比 IRM-02 進保護的電流還大，短路時電源會先保護，所以都不採用。

### 輸入電流（LED 壓降約 1.15V）

| 接法 | 每路 LED 電流 |
|---|---|
| 外部 5VDC | 1.17mA |
| 外部 12VDC | 3.3mA |
| 外部 24VDC | 6.9mA（R 消耗 0.16W，1206 額定 0.25W） |
| 乾接點，用板上 +12V，只有 1 路接通 | 2.26mA |
| 乾接點，用板上 +12V，4 路都接通 | 每路 1.17mA |

最低的 1.17mA 乘上 CTR，還遠大於所需的 73µA。保守估計 CTR 在 1mA 時只剩 60%，也還有約 0.7mA。

## 2. J5 接線

| 腳 | 1 | 2 | 3 | 4 | 5 | 6 | 7 |
|---|---|---|---|---|---|---|---|
| 名稱 | +12V（限流 8mA） | IN1 | IN2 | IN3 | IN4 | COM | GND |

背面絲印印有腳位名稱（正面被端子本體擋住）。

- **乾接點（按鈕、溫控器接點、門磁）：**
  - COM（6）接到 GND（7），在端子上用短線跳接。
  - 每個接點接在 +12V（1）和 INx 之間。
- **NPN 輸出（集極開路，接通時拉到 0V）：**
  - COM 接外部電源的 +5～24V。
  - INx 接感測器的輸出。
- **PNP 輸出（接通時輸出 +V）：**
  - COM 接外部電源的 0V。
  - INx 接感測器的輸出。
  - 不要接板上的 GND，才能保有隔離。
- **隔離說明：** 光耦提供 2.5kVrms 隔離，但前提是外部電源沒有接到 J5 的 +12V 或 GND。用乾接點接法時，外部線路會和板子的 SELV 低壓共地。IRM-02 本身對市電有 4.2kV 的加強絕緣，所以仍然是安全的低壓。

## 3. 佈局與佈線

- **板框：** 只有 x 100～125.9（J5 那一段）的上緣從 y=100 移到 y=90，形成 L 形；P1 前方維持原本 y=100 的板緣。固定孔位置不變（外殼要配合）。
  - 為什麼不整片加長：P1 是「開口朝板邊」的插拔座，插頭和 230V 電線會伸出板緣。第一版 V3.2 整片加長，結果 P1 前方多了 10mm 的板子，上面鋪了低壓 GND 銅（正面 89/90、背面 42/90 個取樣點），插頭底下和低壓銅只隔幾 mm 空氣，**達不到 6.4mm 加強絕緣**。DRC 只量銅箔之間的距離，看不到插頭，所以沒抓到。已改成 L 形，並確認 P1 前方沒有任何走線、過孔或鋪銅。
- **擺件：**
  - J5 放在正面左上，開口朝板邊。它與市電端子 P1 焊盤距離約 13mm，安規規則要求 6.4mm。
  - R15–R18、R23 放在背面、J5 本體正下方，直立在各自的端子腳正上方。
  - U5 放在背面，原本 S1 的位置；LED 腳朝 J5，集極朝 U1。
  - C18–C21 放在背面，每個集極腳的正下方。
- **拆除的既有銅：**
  - Mode_bit0／1 指撥訊號。
  - S1 專用的 GND 支線。
  - P2 的 +3V3 供電（原本沿 y≈102 經過 U5 的位置）。改從 U3 的 VDD 重新接；最近的 C17 貼著射頻禁佈區，所以不用它。
  - U5 範圍內的縫合過孔。
  - 共 21 段，都由 `upgrade_v32_pcb.py` 列出並處理。
- **佈線順序：** 依序佈線的結果和順序有關，以下是一路試出來的做法，原因都寫在腳本註解裡：
  1. **先佈 U5 周邊：** DI_IN、DI_A，再佈 DI_COM。COM 腳和 A 腳交錯排列，只能從 U5 本體下方、兩排焊盤中間橫向連接。
  2. **4 條「集極 → 10nF」短線先佔好位置**，再佈「10nF → U1」的長線。
  3. **長線自動試所有排列：** 中間兩隻腳（U1 第 19、18 腳）很容易被左右兩條的過孔包住，所以讓程式依序嘗試 24 種排列，取第一個全部佈通的。目前是第 17 種：DI_3→DI_4→DI_1→DI_2。
  4. **最後佈電源：** +3V3、+12V、+12V_DI。
- **433 匹配區禁佈：** L3、L4、C15、C16、ANT1 外擴 0.5mm，上下兩層都不讓新走線經過，避免 V3.1 才調好的匹配被改變。
- **縫合過孔：** 只在新區域補了 27 顆（3mm 格點）、3 顆（訊號過孔旁），另外有 1 顆是背面一塊 20.8mm² 的 GND 孤島（夾在 DI 線之間）。
  - 19 個新訊號過孔裡，有 16 個旁邊沒有空位補 GND 回流過孔。DI 是直流慢速訊號，可以接受。

### 這次修掉的佈線器問題（`mains_router.py`，預設值維持舊行為，V2.0／V3.0 的重建結果不受影響）

- **新增 `stamp_r`：** 原本焊盤周圍 1mm 內都算「已接上」，而且這一圈不檢查障礙。細腳焊盤（SOP 0.6mm 寬）會因此造成走線停在焊盤外，甚至壓到別條網路。
- **新增 `keep_cl`：** 細腳模式清除自己焊盤的出腳通道時，會連別條網路的實際銅箔一起清掉，過孔就可能打在別人的線上。
- **封裝內建的禁佈區：** 原本只讀板子層級的禁佈區，漏了 ESP32 天線下方那塊（封裝內建）。
- **`set_board()`：** 格點範圍改成跟著板高變動。
- **另外修掉的流程問題：**
  - 載入沒有 `.kicad_pro` 的暫存板檔再存回正式路徑時，會用預設網路類別蓋掉正式專案設定。現在暫存檔旁一律放一份正式專案檔。
  - `assign_3d.py` 原本每次執行都會多插一行空行。
  - 縫合時會在已有過孔的位置重複放一顆。

## 4. 電源預算（12V，IRM-02-12 額定 167mA）

V3.1 的最壞情況是：3 顆繼電器 PWM 保持、1 顆吸合，加上 Zigbee 發射峰值，約 135mA。V3.2 再加上：

- DI 端子 +12V 的最壞情況（直接短路）：+8mA → **約 143mA（86%）**。
- 4 路乾接點全部接通：+4.7mA。端子 +12V 的電流本來就不會超過 8mA，所以已經包含在上面的 8mA 裡。

## 5. BOM 變化

- 新增 5 種料：TLP290-4（C39031）、3.3kΩ 1206（C26032）、1.5kΩ 1206（C26030）、10nF 0603（C57112，基礎料），以及手焊的 J5 端子（不在 BOM 內）。
- 拿掉 1 種料：S1 指撥開關（C7421516）。
- 合計 28 種、59 顆。

## 6. JLC 網頁 PCBA 報價（2026-10-05，未下單）

用這個分支的 `make_jlc_files.py` 產生下單檔，在 JLC 網頁完整跑一次 PCBA 流程：

- JLC 判讀板子為 2 層、93.08×63.4mm。
- BOM 28 種全部比對成功。
- 3D 檢視器裡 U5（背面 SOP-16）第 1 腳和絲印三角形對齊。

規格和 V3.1 相同：無鉛 HASL、Standard、雙面、Confirm Parts Placement。

| 數量 | PCB | 零件 | 上料費 | 總價 | 每片 | 和 V3.1 比 |
|---|---|---|---|---|---|---|
| 5 | 5.30 | 79.27 | 38.75 | **216.91** | 43.38 | +5.74 |
| 10 | 6.40 | 141.63 | 38.75 | **283.81** | 28.38 | +6.59 |
| 30 | 25.80 | 390.83 | 38.75 | **574.72** | 19.16 | +11.60 |

- 上料費多 $4.65：新增 3 種擴展料（TLP290-4、3.3k 1206、1.5k 1206），少 1 種（S1 指撥）。10nF 是基礎料，不收上料費。
- 開機費 $51.50、鋼網 $16.54 不變。

## 7. 待辦與限制

- **韌體：** DI／DO 模式（全關、按一次、持續 × 自鎖、點動、互鎖）、RF 遙控和 DI 同步、取消指撥，另開 PR。在那之前，V3.2 板子配舊韌體時：
  - DI 不會有任何作用；
  - 原本讀指撥的 IO10／IO11 會因內建上拉讀成 OFF/OFF，所以模式固定是「4 路獨立」。
- **J5 端子封裝：** 用的是 3.5mm 直角插拔座的常見外形（孔徑 1.2mm、深約 7mm），**下單前要對照實際料號核對**；3D 模型高度 8mm 也是估計值。
- **外殼：** 板子變成 L 形：左半段（J5）高 93.08mm、右半段維持 83.08mm；固定孔相對板底的位置不變，外殼要配合修改。
- **打樣後實測：**
  - 5V／24V 輸入時的動作門檻；
  - 長線（數公尺）接乾接點時的雜訊和防彈跳；
  - 433 接收距離是否和 V3.1 一樣（確認新走線沒有影響）。

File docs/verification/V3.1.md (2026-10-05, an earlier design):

# V3.1 驗證報告

V3.1 **只換值、不改佈線**：PCB 只動了 8 顆零件的 Value／LCSC 欄位和標題欄版本。目的是處理 V3.0 留下的三個疑慮：

1. 433MHz 匹配值的響應峰值不在 433.92MHz。
2. 4 顆繼電器同時吸合時，12V 電源超過額定，V3.0 只能用韌體限制最多 3 顆。
3. JLC 的 CPL 角度在背面差 90°（另見 PR「CPL 角度改用 JLC 實際封裝驗證」，V3.0 也受影響）。

| # | 項目 | 方法 | 結果 |
|---|---|---|---|
| 1 | 433 匹配 | 同系列原廠阻抗＋ngspice＋最差情況選值 | 433.92MHz 失配 8.2–12.8dB → **3.1–5.3dB** |
| 2 | 電源 | Omron 規格書＋ngspice＋主機單元測試 | 每顆保持 33.3→**14.4mA**；4 顆最壞 **135mA**＜167mA |
| 3 | ERC | `kicad-cli sch erc` | 0 |
| 4 | DRC＋原理圖一致性 | `kicad-cli pcb drc --schematic-parity` | 錯誤 0、未連線 0、不一致 0；警告只有絲印類，數量與 V3.0 相同（37／53／4） |
| 5 | 韌體 | `make -C firmware/test`、`idf.py build` | 20 tests, 0 failures；編譯 0 warning，映像 555156 bytes |
| 6 | CPL | `scripts/test_make_jlc_files.py`、`make_jlc_files.py --check` | 6 tests OK；Q1–Q4 0°、U4 90°、S1 90°（已在 JLC 3D 檢視器核對） |

## 1. 433MHz 匹配

### 問題

V3.0 的值照 SYN480R 規格書「典型應用」433.92MHz 欄：L1（我們的 L3）27nH、L2（L4）47nH、C1（C15）6.8pF、C2（C16）1.8pF。
拓撲是：天線端並聯 L3∥C16 → 串聯 C15 → 晶片 ANT 腳並聯 L4。V3.0 驗證時用 1kΩ∥1–3pF 當晶片輸入阻抗去模擬，峰值落在 213–231MHz，當時判斷是「阻抗模型可能不準」。

### 晶片輸入阻抗從哪裡來

SYN480R 規格書沒有給輸入阻抗。可以找到的對照：

- **腳位與規格表抄自 Micrel MICRF010**：腳位順序一一對應。規格表裡有三行與 MICRF010／011 逐字相同：「Spurious Reverse Isolation, ANT pin, RSC=50Ω, 30µVrms」、「ZREFOSC 290kΩ」、「IF BW 0.43MHz」。
- **晶振頻率同 MICRF211**：433.92MHz 用 13.52127MHz。

同系列原廠實測值（都已含評估板焊墊寄生）：

| 晶片 | 433.92MHz 輸入阻抗 | 串聯模型 | 來源 |
|---|---|---|---|
| MICRF010 | 13.15 − j107Ω（430MHz） | 13Ω＋3.43pF | [micrf010.pdf](https://ww1.microchip.com/downloads/en/DeviceDoc/micrf010.pdf) Table 2 |
| MICRF211 | 18.6 − j174.2Ω | 19Ω＋2.11pF | [micrf211.pdf](https://ww1.microchip.com/downloads/en/DeviceDoc/micrf211.pdf) Table 4 |
| MICRF220 | 12 − j209Ω | 12Ω＋1.75pF | MICRF220 datasheet Table 6 |

V3.0 用的 1kΩ∥2pF 其實落在這個範圍內，所以**問題不在阻抗模型，而在元件值**。

**推論：** 規格書那組值很可能是 MICRF010 的 L 型匹配（串聯 1.8pF＋並聯 27nH，MICRF010 Table 2）被畫到錯的位置。照 MICRF010 自己的接法，峰值會在 429MHz。

### 選值

拓撲與佈線不動，只在 E 系列可買到的值裡搜尋。目標是以下所有組合的最差情況最小：

- 三個晶片阻抗；
- 電感 ±5%；
- 電容 ±0.1pF；
- 0603 電感 Q 取 40。

腳本是 `scripts/rf_match_opt.py`。第一名是 L3 47n／C16 3.3p／C15 2.7p／L4 33n（最差 5.93dB）。**C16 改取 2.7p**，和 C15 用同一料號，可以少一種擴展料，最差情況只多 0.02dB。

ngspice 交叉驗證（`sim/rf_match.cir`），433.92MHz 失配損耗：

| | MICRF010 阻抗 | MICRF211 阻抗 | MICRF220 阻抗 |
|---|---|---|---|
| V3.0：L3 27n、C16 1.8p、C15 6.8p、L4 47n | 8.2dB（最佳點 214MHz） | 9.6dB | 12.8dB |
| **V3.1：L3 47n、C16 2.7p、C15 2.7p、L4 33n** | **5.3dB** | **3.1dB**（最佳點 414MHz） | **5.3dB**（最佳點 434MHz） |

改善 3–7.5dB，等於接收靈敏度多 3–7.5dB。如果晶片阻抗恰好接近其中一顆，專門針對它的值可以更好（例如 MICRF211 原廠值在 MICRF211 阻抗下是 1.6dB）。但換成另一種阻抗會變成 7dB 以上，所以不押單一顆。

| 位號 | V3.0 | V3.1 | LCSC |
|---|---|---|---|
| C15 | 6.8pF C0G | 2.7pF C0G ±0.1pF | C162221（Murata GRM1885C1H2R7BA01D） |
| C16 | 1.8pF C0G | 2.7pF C0G ±0.1pF | C162221 |
| L3 | 27nH | 47nH ±5% | C29683（Sunlord SDCL1608C47NJTDF，V3.0 的 L4） |
| L4 | 47nH | 33nH ±5% | C35050（Sunlord SDCL1608C33NJTDF） |

**打樣後要做：** 用 VNA 量 ANT1 的 S11，或用遙控器實測距離。真實阻抗確定後，用 `scripts/rf_match_opt.py` 改 `ZCHIP` 重算；四顆都是 0603，可以直接換值。

## 2. 電源：繼電器 PWM 降壓保持

### 依據

Omron G5Q-1 規格書（[en-g5q.pdf](https://omronfs.omron.com/en_US/ecb/products/pdf/en-g5q.pdf)，J155-E1-16）：

- p.2：12VDC 線圈 360Ω、33.3mA；Must operate 75% max.。
- **p.6：** 「first apply the rated voltage to the coil for at least 100 ms」，「at least … 30% (G5Q-1 type) of the rated voltage is required for the coil holding voltage」。
- p.6 的 PWM 段落寫給 **-PW 型**：驗證條件是 Duty ≥50%、≥10kHz、續流二極體 Vf ≤0.4V，並註明要實機確認。**標準版 G5Q-1 沒有 PWM 背書**，而 G5Q-1-PW 在 JLC 無料。

所以 V3.1 照 -PW 的驗證條件來設計：

- 全壓 100ms，之後 20kHz、60% duty 保持；
- 續流二極體改 Schottky **B5819W**（C8598，JLC 基礎料、同 SOD-123），Vf 約 0.3V@20mA。

### 模擬（`sim/relay_pwm_hold.cir`）

| 量測 | 結果 |
|---|---|
| 吸合時 12V 電流 | 33.3mA |
| **保持時 12V 電流（平均）** | **14.4mA** |
| 保持時線圈平均電壓 | 12 − 4.34 = 7.66V（額定 64%，Omron 下限 30%） |
| Vds 峰值（PWM 中／關斷） | 12.3V／12.3V（Si2302 耐壓 20V） |
| 關斷後線圈電流降到 1mA | 1.4ms |

公式估計是 11.8mA。模擬比較高，是因為閘極 1k 電阻配上 MOSFET 電容，關斷晚約 1µs，實際 duty 約 64%。單元測試用 66% 當最壞情況重算預算。

CI 守門：保持電流必須 < 17mA，Vds 峰值必須 < 20V。

### 預算（12V 側；Zigbee 收訊等常態 26mA，+10dBm 發射峰值 +32mA）

| 情況 | 12V 側 | 判定 |
|---|---|---|
| 4 顆保持＋發射峰值 | 26＋32＋4×14.4 ≈ 116mA | 額定 70% |
| 3 顆保持＋1 顆吸合＋發射峰值（最壞） | 26＋32＋3×14.4＋33.3 ≈ 135mA | 額定 81% |
| V3.0（全壓）：4 顆＋發射峰值 | 191mA | 超過 110% 保護點 |

韌體吸合錯開 110ms（大於 100ms 吸合時間），所以同時最多 1 顆在全壓。

### 韌體

- `fa_coil`（純 C）：吸合／保持 duty、線圈電壓、電源電流與預算。3 個新的主機單元測試涵蓋：
  - 時序；
  - 保持電壓 ≥30%；
  - 4 顆預算在 IRM-02 額定內；
  - 沒有 PWM 時會超額。
- `app_main.c`：LEDC 10-bit、20kHz 驅動 IO6／IO7／IO0／IO1。每顆用一個 esp_timer 在 100ms 後切到保持。保持回呼和關閉命令用互斥鎖保護，避免「剛關掉又被設回保持」。
- Kconfig：
  - 新增 `FA_RELAY_PWM_HOLD`（預設 y）、`FA_RELAY_PULLIN_MS` 100（範圍 100–1000）、`FA_RELAY_HOLD_PCT` 60（範圍 50–100）、`FA_RELAY_PWM_HZ` 20000。
  - `FA_MAX_RELAYS_ON` 開 PWM 時預設 4，`FA_RELAY_STAGGER_MS` 預設 110。
- **編譯期防呆：**
  - 關掉 PWM 卻讓上限 > 3，會編譯失敗（已實測：產生 `#error`）。
  - 吸合間隔 ≤ 吸合時間，也會編譯失敗。
  - 原因：menuconfig 改其中一項時，另一項不會跟著變。

**打樣後要做：** 在最高環境溫度下，4 顆全吸，持續 Zigbee 發射：

- 量 IRM 輸出有沒有進 hiccup；
- 加振動確認不會掉；
- 量釋放時間（只用二極體續流會比無抑制慢，TE 13C3311 實測約 6.5 倍）。

## 3. 原理圖／PCB

```text
$ python scripts/gen_schematic.py 3.1        （kicad-sch-api）
V3.1: 59 顆零件, 163 標籤, 15 no-connect
$ kicad-cli sch erc --severity-error --exit-code-violations ...
Found 0 violations
$ python3 scripts/drc_summary.py
errors: {}
warnings: {'silk_overlap': 37, 'silk_over_copper': 53, 'silk_edge_clearance': 4}
unconnected: 0  parity: 0
```

PCB 的 diff 只有 C15、C16、L3、L4、D1–D4 的 Value／LCSC 和標題欄 `rev 3.1`，佈線、鋪銅、過孔都沒動（沒有重跑 Freerouting）。

`Device:D_Schottky` 的接腳與 `Diode:1N4148W` 相同（1＝K、2＝A），網路不變。

## 4. BOM 變化

- 26 種 → 25 種。
- 擴展料：少了 C1679、C1640、C12100，多了 C162221、C35050；L3 改用原本 L4 的 C29683。
- 二極體 C81598 → C8598，都是基礎料。

## 5. JLC 網頁 PCBA 報價（2026-10-05，未下單）

用這個分支 `make_jlc_files.py` 產生的 Gerber／BOM／CPL，在 JLC 網頁完整跑一次 PCBA 流程。上傳後：

- BOM 25/25 全部比對成功，都是 JLC 現貨、沒有替代料。
- 3D 檢視器裡背面 Q1–Q4、U4、S1、D1–D4 一上傳就正確，不用手動旋轉。

規格：2 層 1.6mm、無鉛 HASL、1oz；Standard PCBA、雙面組裝；Confirm Parts Placement＝Yes，並勾「不自動確認」。USD，不含運費。

| 數量 | PCB | 零件 | 開機費 | 上料費 | 鋼網＋治具 | 組裝／手焊等 | **總價** | **每片** | 重量 |
|---|---|---|---|---|---|---|---|---|---|
| 5 | 5.20 | 78.62 | 51.50 | 34.10 | 33.08 | 8.67 | **211.17** | **42.23** | 1.56kg |
| 10 | 6.40 | 140.29 | 51.50 | 34.10 | 33.08 | 11.84 | **277.22** | **27.72** | 2.51kg |
| 30 | 23.60 | 387.70 | 51.50 | 34.10 | 41.35 | 24.87 | **563.12** | **18.77** | 5.63kg |

- **雙面組裝的固定成本約 $119**：開機費、上料費、鋼網、治具。這是小量時單價高的主因。
- 背面 32 顆都是被動件、MOSFET、二極體和降壓 IC。若下一版改成單面擺件，可以省一次開機費和一面鋼網。
- **30 片起**，JLC 自動把「確認擺件」「確認生產檔」設成免費必選。
- 運費要進購物車才會計算。
- P1／P2／P3 端子與 F1 保險絲座沒有 LCSC 料號，不在 BOM 內，要自己焊。

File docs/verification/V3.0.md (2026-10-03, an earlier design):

# V3.0 設計驗證報告

對象：標籤 `v3.0`（ESP32-C6＋SYN480R）。日期 2026-10-03。
V3.0 只改低壓區，市電、電源、繼電器驅動沿用 V2.0；V2.0 已驗證、這次電路沒變的項目（市電間距、走線載流、繼電器關斷尖峰）沿用 [V2.0 報告](README.md)，下表註明「沿用」。

## 總表

| # | 項目 | 工具 | 結果 | 判定 |
|---|---|---|---|---|
| 1 | ERC | kicad-cli | 0 錯誤 | ✅ |
| 2 | DRC＋市電安規 `.kicad_dru` | kicad-cli | 0 錯誤、0 未連線 | ✅ |
| 3 | 原理圖／PCB 一致 | kicad-cli | 0 | ✅ |
| 4 | BOM：貼片件都有 LCSC 料號 | kicad-cli BOM | 26 種貼片件全有；手焊 F1、P1、P2、P3、ANT1（同 V2.0 做法） | ✅ |
| 5 | 主料 JLC 庫存（2026-10-03 即時查） | jlcpcb.com 零件庫 | ESP32-C6-WROOM-1-N8 3451、SYN480R 8199、晶振 1875 | ✅ |
| 6 | 電源預算 | 規格書手算 | 預設 ≤3 顆吸合：峰值 158mA ＜ 額定 167mA；4 顆峰值 191mA 超過保護點 | ⚠️ 韌體限制 |
| 7 | 433MHz 匹配網路 | ngspice `sim/rf_match.cir` | 433.92MHz 電壓增益 +4.6～+6.0dB；響應峰值在 210–230MHz | ⚠️ 要實測 |
| 8 | 繼電器驅動、LED（SPICE） | 沿用 V2.0 | 閘極仍是 3.3V GPIO 經 1k，電路相同 | ✅ 沿用 |
| 9 | EMC 預檢（CISPR 32 B） | kicad-happy emc | 14 項、0 錯誤、4 警告；與 V2.0 同指令結果完全相同 | ✅ |
| 10 | 3D／STEP | Jobset | 成功；ESP32 模組高 3.1mm（ZS3L 估 3.3mm） | ✅ |
| 11 | Jobset 一鍵產出 | KiCad Jobset | 8/8 成功（修好 BOM 空檔問題） | ✅ |
| 12 | 韌體單元測試 | gcc＋ASan/UBSan | 17/17 通過 | ✅ |
| 13 | 韌體編譯 | ESP-IDF v5.5.4＋esp-zigbee-lib 2.0.4 | 成功、0 警告；映像 544KB（app 分割區 2MB） | ✅ |

## 1–3. ERC／DRC／parity

```text
$ kicad-cli sch erc --severity-error --exit-code-violations WO30109_FreshAir.kicad_sch
Found 0 violations                                   exit=0
$ kicad-cli pcb drc --schematic-parity --severity-error --exit-code-violations WO30109_FreshAir.kicad_pcb
Found 0 violations / 0 unconnected items / 0 schematic parity issues   exit=0
```

Freerouting 第一組（40 輪）就全部接通。它的 DSN 不含 `.kicad_dru` 的板邊 0.5mm 規則，第一次 DRC 有 3 段 GND 走線貼左上板邊；`scripts/fix_edge_tracks.py` 刪掉後由 GND 鋪銅接回，已併入 `build_v30.sh`。

## 4–5. BOM 與庫存

| LCSC | 料件 | 用途 | JLC 庫存 |
|---|---|---|---|
| C5366877 | ESP32-C6-WROOM-1-N8 | MCU＋Zigbee | 3451 |
| C916347 | SYN480R（JSMSEMI） | 433MHz 接收 | 8199 |
| C654957 | TXC 7B013521R01 13.52127MHz 20pF | SYN480R 晶振 | 1875 |
| C12100 / C29683 | Sunlord SDCL1608 27nH / 47nH | 匹配電感 | 44 萬 / 9 萬 |
| C1679 / C1640 | 6.8pF / 1.8pF C0G 0603 | 匹配電容 | 19 萬 / 7 萬 |
| C21189 | 0R 0603 | R14 關靜噪 | 基本料 |

備選（同功能、也在 JLC）：ESP32-C6-MINI-1-N4（C5736265，469）、ESP32-C6-MINI-1U-H4（C20627095，外接天線，2396）；CMT2210LB（C177240，靈敏度 −113dBm）。ESP32-H2 系列模組 JLC 全部 0 庫存。

## 6. 電源預算

IRM-02-12：額定 12V 167mA；超過 110%（約 184mA）進入 hiccup 保護（規格書 OVERLOAD 欄）。規格書沒有列最大容性負載，所以不靠外加大電容吸收峰值。

| 負載（3.3V 側 → 12V 側，降壓效率取 88%） | 12V 側 |
|---|---|
| ESP32-C6 802.15.4 收訊 73mA（路由器一直在收） | 23mA |
| SYN480R 3.5mA、LED ~5mA、其他 | 3mA |
| 發射 +10dBm 峰值，比收訊多約 100mA（規格書 0dBm 117mA／+12dBm 185mA 內插） | +32mA，封包期間 ≤4ms |
| G5Q 線圈 33.3mA／顆 | 33mA × n |

| 同時吸合 | 持續 | 發射峰值 |
|---|---|---|
| 1（風速模式常態） | 59mA | 91mA |
| 3（**韌體預設上限**） | 126mA | 158mA |
| 4 | 159mA | 191mA（超過保護點） |

**結論**：不改硬體，韌體預設同時吸合 ≤3 顆、發射 +10dBm、不啟動 Wi-Fi。三個風速模式本來最多同時吸 3 顆，只有「4 路獨立」模式會被限制。要 4 顆全吸，換 IRM-03-12（C6640065，250mA）——但它腳位完全不同，市電要重新佈線，列為下一版。

## 7. 433MHz 匹配網路（`sim/rf_match.cir`）

網路照 SYN480R 規格書 433.92MHz 典型應用：天線 → C16 1.8pF∥L3 27nH → C15 6.8pF 串聯 → L4 47nH∥晶片 ANT 腳。規格書**沒有給晶片輸入阻抗**，所以用 1kΩ∥C_in（1／2／3pF）加 0.3pF 焊墊寄生去掃：

| C_in | 響應峰值 | 433.92MHz 增益 | 315MHz 增益 |
|---|---|---|---|
| 1pF | 231MHz、+11.4dB | +6.0dB | +7.2dB |
| 2pF | 222MHz、+11.8dB | +5.3dB | +6.4dB |
| 3pF | 213MHz、+12.1dB | +4.6dB | +5.6dB |

（增益＝晶片輸入端電壓相對 50Ω 匹配時的 0.5V）

**判讀**：這組數值在 433.92MHz 能送進訊號（+4.6～+6dB），但響應很寬、峰值落在 200 多 MHz，並不是尖銳地對準 433.92MHz。原因可能是實際輸入阻抗與假設不同，模擬無法定論。**打樣後要用 VNA 量 ANT1 的 S11，或用遙控器實測距離，必要時微調 C15／C16**（同封裝直接換值）。

## 8. 繼電器驅動、LED

閘極驅動從 STM32 GPIO 換成 ESP32-C6 GPIO，兩者都是 3.3V，經同一顆 R5–R8 1k、R9–R12 10k 下拉，Si2302 在 Vgs=3.3V 的導通條件不變，V2.0 的 `sim/relay_driver.cir`（關斷尖峰 12.8V）直接適用。LED 經 R4 100Ω 由 IO2 驅動，電流 3.8–7.1mA（V2.0 `sim/led.cir`），在 ESP32-C6 GPIO 能力內。

開機安全：繼電器接 IO6／IO7／IO0／IO1，都不是 strapping 腳；閘極有 10k 下拉，開機到韌體設定 GPIO 前不會吸合。

## 9. EMC 預檢

用同一組指令跑 V2.0 與 V3.0：

```text
analyze_schematic.py → analyze_pcb.py → analyze_emc.py --standard cispr-class-b
V2.0：14 findings（0 error / 4 warning / 10 info）
V3.0：14 findings（0 error / 4 warning / 10 info）— 規則與數量完全相同
```

4 個警告：GND 鋪銅比例低（×2，市電 6.4mm 隔離帶造成，刻意的）、RV1 離 P1 偏遠、U4 降壓諧波落在 30–88MHz。換晶片沒有帶來新風險。
（V2.0 報告寫的「49/100、63 項」是用不同參數跑的，同指令重跑兩版結果相同，以本節為準。）

ESP32-C6 天線：模組天線端貼左板邊，`Espressif_ESP32-C6-WROOM-1` 封裝內建兩層禁銅區（含板邊外 1mm），DRC 確認區內無銅。

## 10–11. 3D、Jobset

`kicad-cli jobset run`：8/8 成功（ERC、DRC、Gerber、鑽孔、座標、BOM、原理圖 PDF、STEP）。原本 jobset 的 BOM 欄位設定是空的，產出 0 位元組，V3.0 一併修好（欄位、分組與 CI 一致）。

## 12. 韌體單元測試

```text
$ make -C firmware/test
17 tests, 0 failures
```

涵蓋：指撥模式、4 種互鎖群組、先斷後通與 200ms 間隔、同時吸合上限、風速循環、EV1527 解碼（含 ±20% 脈寬抖動、不同 T、雜訊與單幀不回報）、遙控器學習表（去重、滿了擠掉最舊）、按鍵短按／3 秒／10 秒分類。

## 13. 韌體編譯

```text
$ . ~/esp/esp-idf-v5.5.4/export.sh && idf.py set-target esp32c6 && idf.py build
Project build complete.          （0 warning）
Total image size: 544330 bytes   Flash code 464KB；DIRAM 90KB／452KB（19.9%）
esp-zigbee-lib 2.0.4（component manager 解析）
```

sdkconfig 確認：`CONFIG_FA_MAX_RELAYS_ON=3`、`CONFIG_FA_ZB_TX_POWER=10`、`CONFIG_ZB_ZCZR=y`（路由器）、`CONFIG_ZB_RADIO_NATIVE=y`、flash 8MB。
編譯通過只代表 API 用法與型別正確；入網、互鎖時序、433 解碼要上板驗證（見待辦）。
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

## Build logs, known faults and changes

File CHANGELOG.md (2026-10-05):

# 變更紀錄

格式參考 [Keep a Changelog](https://keepachangelog.com/zh-TW/1.1.0/)，版號用 `硬體大版.小版`。

## [3.0] — ESP32-C6 單晶片＋SYN480R

把 Tuya ZS3L（JLC 無料）與 Ebelong EPA09-4D（無規格書、JLC 無料）換成 JLC 有庫存、可直接貼片的料，順便把 STM32 拿掉。

### 電路
- U1：STM32F103C8T6 ＋ U3 Tuya ZS3L → **ESP32-C6-WROOM-1-N8**（C5366877）。ESP32-C6 內建 IEEE 802.15.4，直接跑 Zigbee 3.0（ESP-Zigbee SDK），也有 Wi-Fi 6／BLE 5。ESP32-H2 模組在 JLC 全部 0 庫存，所以選 C6。
- RF1：EPA09-4D（4 路已解碼模組）→ **U3 SYN480R**（C916347，JSMSEMI）＋Y1 13.52127MHz/20pF（C654957）＋LC 匹配（C15 6.8pF、C16 1.8pF、L3 27nH、L4 47nH），照規格書 433.92MHz 典型應用。SHUT 接地（常開）、SQ 經 R14 0R 接地（關靜噪，靈敏度多 3dB）。**遙控器解碼（EV1527/PT2262）改由 ESP32 韌體做**（RMT 或 GPIO 中斷量脈寬），可學習多支遙控器。
- ANT1：433MHz 天線焊點（1/4 波長 17.3cm 導線或彈簧天線，手焊；JLC 無 433 天線庫存）。
- 腳位：繼電器 IO6/IO7/IO0/IO1（避開 strapping 腳，閘極 10k 下拉保證開機時不吸合）、指撥 IO10/IO11、燈 IO2、433 資料 IO23、按鍵 IO9。
- B1 改接 IO9（BOOT）：上電時按住＝進下載模式，平時當配對／重置鍵；R2 10k 上拉。IO8 加 R3 10k 上拉（下載模式需要 IO8=1）。EN 用 R1 10k／C5 1µF 延遲（Espressif 建議值）。
- P2：SWD 1×4 → 燒錄座 2×3（3V3、GND、TXD0、RXD0、EN、BOOT），接 USB-UART 轉接板用 esptool 自動燒錄。1×6 直排會壓到 H3 固定孔，所以改 2×3。
- 移除：C3、C4、C10、R13、TP1，與 ZS3L↔STM32 交握線 Input_1–4／Output_1–4。
- 新增自訂符號 `ESP32-C6-WROOM-1`、`SYN480R`、`Crystal_4P`（`scripts/make_symbols.py`）與封裝 `Espressif_ESP32-C6-WROOM-1`（依規格書 v1.4 Fig.10-1，含天線下方兩層禁銅區）。

### PCB
- 市電區、繼電器、電源、端子、固定孔完全沿用 V2.0（`scripts/upgrade_v30_pcb.py` 從 git 標籤 `v2.0` 的 PCB 開始，**不需要原始 Gerber**）。
- ESP32-C6 模組放在原 ZS3L 位置（左緣），天線端貼板邊、下方禁銅；SYN480R 放在原 RF1 位置，ANT 腳朝右，433 天線焊點遠離 ESP32 天線。
- 一鍵重建：`scripts/build_v30.sh`。

### ⚠️ 電源預算（要韌體配合）
IRM-02-12 額定 12V 167mA。ESP32-C6 Zigbee 發射 +12dBm 峰值 185mA@3.3V，折合 12V 側約 58mA（降壓效率 88%）；4 顆繼電器全吸 133mA → 峰值約 192mA，**超過額定**。
- 修正計算：路由器常態是**收訊** 73mA（12V 側 23mA），4 顆全吸持續 159mA 在額定內；超額的是發射峰值。韌體預設同時吸合 ≤3 顆、發射 +10dBm（峰值 158mA）、不啟動 Wi-Fi。
- 硬體根治：下一版改 IRM-03-12（250mA，C6640065），但封裝腳位完全不同，市電要重新佈線。

## [3.4] — 照外殼 4-02-3 放回原板框

外殼是精鋼塑模 **4-02-3**（35mm 導軌盒，外形 88×72×59mm，螺絲間距 50×50mm）。原板 63.4×83.08mm 本來就是照它做的。V3.2（加高到 93mm）、V3.3（加高到 107mm）**放不進外殼**，V3.3 的板上 NFC 線圈也離前蓋太遠、讀不到。完整依據：[V3.4 驗證報告](docs/verification/V3.4.md)。

### 電路
- **J5**：改 2.54mm 7P（KEFA KF2EDGR-2.54-7P，C577599），和 P1 共用上方開窗；焊盤離市電 9.08mm。
- **NFC**：拿掉板上線圈，改 **J6**（JST SH 2P，C160388）接 FPC 天線貼前蓋內側；C22／C24 依天線電感選值，預設不上件。
- **P2**：排針改背面 2×3 燒錄測試點。
- **B1**：改 TS-1088（C720477，基礎料），放在 J5 後方（開蓋才按得到；學遙控器、恢復出廠可改用 NFC App）。
- **GPIO**：和 V3.3 相同，韌體不用改。

### PCB
- 板框 63.4×83.08mm、固定孔不變。`scripts/build_v34.sh`：從 V3.1 換件擺件，低壓全部交給 Freerouting 重佈。
- ERC 0；DRC 錯誤 0、未連線 0、原理圖一致性 0。
- CPL：J6 照規則表會是 0°，以 JLC 封裝驗證後改成 180°。

### 工具
- `mains_router.board_height()` 改用板框線段端點計算（原本會把板邊線寬算進去，格點偏 0.05mm）。
- 新封裝：`TerminalBlock_Pluggable_1x07_P2.54mm_Horizontal`（含 3D 模型）、`ProgPads_2x03_P2.54mm`、`SW_SPST_TS-1088`。
## [3.3.1] — NFC 設定韌體

- **協定與驗證**（純 C、主機可測）：
  - `fa_nfc`：STATE／REQUEST／ACK 格式、gen 樂觀鎖、HMAC 簽章、mailbox 指令（GET_STATUS、IDENTIFY、LEARN_REMOTE、FACTORY_RESET，以 challenge 防重送）。
  - `fa_sha256`：SHA-256／HMAC-SHA256。
- **為什麼由 ESP32 驗簽**：ST25DV 的 RF 密碼 I2C 端無法設定（規格書 Table 60），所以不用晶片的 RF 寫保護，改由 ESP32 驗簽。每台 8 位數 PIN 第一次開機產生、存 NVS。
- **ESP32 端**：
  - `st25dv.c`：I2C 驅動（16-byte 分列寫入＋ACK polling、I2C 密碼開 FTM、mailbox）。
  - `fa_nfc_port.c`：每 100ms 輪詢。
  - `app_main`：套用設定時，若互鎖分組改變就先全關再重新分組。
- **板子版本與腳位**：`board.h` 以 menuconfig 選 V3.3／V3.2；V3.3 的 DI 接 IO3／IO15／IO22／IO21、NFC I2C 接 IO20／IO19。
- **給 App 開發**：[`docs/nfc-protocol.md`](docs/nfc-protocol.md) 規格，以及 [`tools/nfc_ref.py`](tools/nfc_ref.py) 參考實作（只用標準函式庫）。
- **驗證**：
  - 主機測試 36 個：SHA-256 用 FIPS 180-2 向量、HMAC 用 RFC 4231 case 2／6、CRC 用 CCITT 檢查值；C 與 Python 逐 byte 對照測試向量。
  - `idf.py build` 在 V3.3 與 V3.2 兩種設定下都是 0 warning。

## [3.3] — NFC 設定介面（ST25DV04KC＋板上印刷線圈）

手機 App 貼近板子即可讀寫進階設定（DI／DO 模式、點動時間、遙控器清單），Apple／Google 使用者不用 Wi-Fi 熱點、Matter 也不必斷線。完整依據：[V3.3 驗證報告](docs/verification/V3.3.md)。

### 電路
- **U6 ST25DV04KC**（C3304276）：ISO 15693 NFC＋I2C，4Kbit EEPROM、256B mailbox。GPO 不接（韌體輪詢），V_EH 不用。
- **L5 板上印刷線圈**：14.9×14.6mm、8 圈、0.2／0.2mm，1.277µH（`scripts/nfc_coil.py`，以實際封裝銅箔計算）。
  - C22 75pF C0G（C1681）＋晶片內建 28.5pF → 13.84MHz。
  - C24 微調空位（不上件）。
- **I2C**：SDA＝IO20（U1 第 18 腳）、SCL＝IO19（第 17 腳），各接 10k 上拉；C23 100nF 去耦。
- **DI_1–4 改接 IO3／IO15／IO22／IO21**：和 I2C 照左右順序排，佈線不交叉。**韌體 `board.h` 要跟著改**（NFC 韌體 PR）。

### PCB
- **J5 改到左側板邊**：DI 電線改從左側出，由下往上依序是 +12V、IN1–4、COM、GND。左上角留給 NFC 線圈；左半段上緣提高到 107.2mm（右半段維持 83.08mm）。
- **一支腳本重建兩版**：`scripts/upgrade_v32_pcb.py` 以 `WO_VER=3.2／3.3` 切換，兩版都從 V3.1 重建。
- **線圈封裝** `WOOW:NFC_Coil_14.9x14.6mm_8T`：net tie，禁布區上下兩層禁止鋪銅和過孔。背面跨線由腳本畫成真正的走線。
- **驗證**：ERC 0；DRC 錯誤 0、未連線 0、不一致 0。

### 工具
- **`mains_router.py`**：
  - 禁布區外擴半線寬；
  - 禁止鋪銅的禁布區也算障礙；
  - 讀真實（L 形）板框。
- **`add_stitching.py --prune`**：同時移除懸空的 GND 過孔。
- **`make_footprints.py`**：新增 `nfc_coil()` 產生器。
## [3.2.1] — DI／DO 模式韌體

- 新增 `fa_io`（純 C）：每路 DI（全關／按一次／持續）× DO（自鎖／點動／互鎖），固定 1 對 1；遙控器 4 鍵＝DI1–4 的分身（同一組設定、狀態取「或」，200ms 沒收到幀＝放開）。11 個主機單元測試（共 31 個）。
- `fa_relays` 互鎖群組改由 DO 模式決定（`fa_relays_init_group`），取代指撥；按鍵風速循環跟著這組。
- `board.h`：DI1–4 = IO22/IO21/IO20/IO19；拿掉指撥腳。設定存 NVS `fa/io_cfg`，出廠預設由 menuconfig 選（預設三段風速＋1 路、DI 持續、點動 1 秒），恢復出廠一併清除。
- `idf.py build` 0 warning（556738 bytes）。

## [3.2] — 4 路光耦 DI 輸入、拿掉指撥

板子上緣左半段加長 10mm 放 4 路 DI（L 形，P1 前方維持原板緣）；市電區、繼電器區佈線不動。完整依據：[V3.2 驗證報告](docs/verification/V3.2.md)。

### 電路
- **J5**：7P 3.5mm 插拔端子，腳位 +12V／IN1–IN4／COM／GND。
  - 可接乾接點，也可接 5–24VDC（NPN、PNP 輸出都可以）。
  - +12V 經 **R23 1.5k** 限流，短路最多 8mA，可長期短路。
- **U5 TLP290-4**（C39031）：交流輸入光耦 ×4，隔離 2.5kVrms。輸入電阻 R15–R18 3.3k 1206，集極接 10nF（C18–C21）。
- **DI1–DI4**：接 IO22／IO21／IO20／IO19（U1 上排），用 ESP32 內建上拉，不另加上拉電阻。
- **拿掉 S1 指撥開關**：IO10／IO11 空出，模式改成軟體設定（韌體另開 PR）。

### PCB
- `scripts/upgrade_v32_pcb.py`：從 V3.1 的 PCB 一鍵重建，不跑 Freerouting。
  - 用格點 A* 佈新網路，和市電保持 6.5mm。
  - 433 匹配區上下兩層都設禁佈。
  - DI 長線自動試所有佈線順序。
  - 在新區域補縫合過孔，並自動接回 GND 孤島。
- ERC 0；DRC 錯誤 0、未連線 0、原理圖一致性 0。
- 板子變成 L 形：只有 J5 那一段上緣加高 10mm（83.08 → 93.08mm），P1（AC IN）前方維持原板緣，讓插頭與 230V 電線不會壓在低壓 GND 鋪銅上（固定孔不動，外殼要配合）。

### 工具修正
- `mains_router.py`：
  - 新增 `stamp_r`：細腳焊盤要真的接到焊盤中心。
  - 新增 `keep_cl`：清除自己焊盤的出腳通道時，別條網路的銅照樣算障礙。
  - 讀取封裝內建的禁佈區（ESP32 天線下方）。
  - 新增 `set_board()`：格點範圍跟著板高變動。
  - 以上預設值都維持舊行為。
- `add_stitching.py`：新增 `STITCH_REGION`（只在指定範圍加過孔）與 `--islands`（接回 GND 孤島）。
- `assign_3d.py`：改成冪等，不會每次多插一行空行。
- `make_jlc_files.py`：`--refresh-footprints` 預設只抓快取裡沒有的料號，並刪掉 BOM 已經不用的料號。
- `test_make_jlc_files.py`：BOM 已經不用的料號（S1），JLC 焊盤直接寫在測試裡。

## [3.1] — 433 匹配重新選值、繼電器 PWM 降壓保持

只換值、不改佈線（PCB 只動 8 顆的 Value／LCSC）。完整依據與模擬：[V3.1 驗證報告](docs/verification/V3.1.md)。

### 電路
- **433 匹配**：C15 6.8p→2.7p、C16 1.8p→2.7p（C162221，±0.1pF）、L3 27n→47n（C29683）、L4 47n→33n（C35050）。規格書典型應用值用同系列 Micrel 原廠實測輸入阻抗算，峰值落在 210–230MHz，433.92MHz 失配 8–13dB；新值以「三個晶片阻抗 × 元件公差」最差情況選出，失配 3.1–5.3dB（`scripts/rf_match_opt.py`、`sim/rf_match.cir`）。
- **D1–D4**：1N4148W → B5819W Schottky（C8598，基礎料、同 SOD-123），Vf 約 0.3V，符合 Omron PWM 保持驗證條件（≤0.4V）。

### 韌體
- **繼電器 PWM 降壓保持**（`FA_RELAY_PWM_HOLD`，預設開）：全壓 100ms 後改 LEDC 20kHz、60% 保持，每顆 12V 端 33.3→14.4mA（`sim/relay_pwm_hold.cir`）。`FA_MAX_RELAYS_ON` 預設 3→4，4 顆全開最壞約 135mA＜IRM-02-12 額定 167mA。
- 新增 `fa_coil` 模組與 3 個主機單元測試（共 20 個）；關掉 PWM 卻設 4 顆、或吸合間隔 ≤ 吸合時間會編譯失敗。

### CI
- KiCad CI 的 SPICE 步驟加跑 `relay_pwm_hold.cir`，守門：保持電流 < 17mA、Vds 峰值 < 20V。

### ⚠️ 打樣要驗證
- 433：VNA 量 S11 或遙控器實測距離（晶片真實阻抗原廠沒公開）。
- PWM 保持：標準版 G5Q-1 沒有 Omron 的 PWM 背書（-PW 型才有，JLC 無料）；最高溫＋振動下實測保持與釋放。

## [3.0.3] — CPL 角度改用 JLC 實際封裝驗證

### 修正（會直接做出壞板）
- 在 JLC 下單頁 3D 檢視器逐顆核對 V3.0 的 CPL，背面 **Q1–Q4、U4、S1 都差 90°**（腳伸出方向和焊盤垂直）。原因：matthewlai 規則表依「封裝名稱」比對，但 JLC 擺件用的是**該 LCSC 料號自己的 EasyEDA 封裝**；C5224182 的 `SOT-23-3…BR` 要 180°（表上 −90°）、C780769 的 `TSOT-26` 要 270°（表上 180°）、C7421516 的 DIP 開關要 270°（表上沒有規則）。
- 正確角度：Q1–Q4 0°、U4 90°、S1 90°（原本 90°、0°、180°）。其他零件和 3D 檢視器一致。

### 改進
- `hardware/WO30109_FreshAir/jlc_footprints.json`：BOM 26 種料號在 EasyEDA 庫的焊盤座標快取（CI 不連 EasyEDA，它連續抓約 20 筆就回 403）。
- `make_jlc_files.py`：角度優先用快取的 JLC 封裝依焊盤編號比對 0/90/180/270 求解（正面 板上=R(θ)·E；背面 板上=MirrorX·R(θ)·E，已在 JLC 檢視器實測），唯一解才採用；對稱件、焊盤編號對不上、沒有快取才退回規則表，並列出「角度沒有經過驗證」的零件（目前 B1、RV1、U2，都是對稱或腳位不對稱的通孔件，插反裝不進去）。模組散熱焊盤被 EasyEDA 拆成多個編號時，容許剔除 10% 焊盤。
- 新增 `--refresh-footprints`（換料後更新快取，需 `pip install easyeda2kicad`）與 `--check`（有料號沒快取就失敗）。
- `scripts/test_make_jlc_files.py`：6 個單元測試（真實的 U3、Y1、D1、Q1、U4、S1 焊盤＋鏡像、對稱、散熱焊盤離群等情況）。KiCad CI 新增「JLC 下單檔」步驟，跑測試＋`make_jlc_files.py --check`，產物附在 artifact 的 `jlc/`。

## [3.0.2] — JLC 下單檔

- `scripts/make_jlc_files.py`：一次產出 JLC 的 Gerber＋鑽孔 zip、BOM、CPL（`output/jlc/`）。CPL 位置取焊盤中心、背面角度鏡射，旋轉修正用 matthewlai `cpl_rotations_db.csv`（與 kicad-jlcpcb-tools 相同比對規則）；沒有規則的自訂封裝（U1、K1–K4、B1）會列出來，下單時要在 JLC 預覽確認。
- JLC API 預審：2 層、63.4×83.08mm、無紅／黃警示。

## [3.0.1] — V3.0 韌體與驗證

- **韌體** `firmware/`（ESP-IDF v5.5.4＋esp-zigbee-lib v2）：Zigbee 3.0 路由器、4 個 On/Off 端點；指撥 4 種模式（4 路獨立／三段風速＋1／兩段風速＋2／4 路互斥）與先斷後通互鎖；同時吸合上限、線圈吸合錯開 50ms、發射 +10dBm；SYN480R 邊緣中斷＋EV1527 解碼、遙控器學習（NVS 存 8 支）；B1 短按風速循環、3 秒學習、10 秒恢復出廠；L1 狀態燈。
- 純邏輯 `firmware/components/fa_core/` 主機端單元測試 17 項（gcc＋ASan/UBSan）。
- CI：新增 `firmware-ci.yml`（單元測試＋`espressif/idf:v5.5.4` 編譯，產出 .bin）。
- 驗證報告 `docs/verification/V3.0.md`：電源預算、433 匹配模擬（`sim/rf_match.cir`）、EMC、BOM／庫存、Jobset。
- Jobset 的 BOM 原本欄位空白、產出 0 位元組，已修正。

## [2.0.1] — 設計驗證

- 完整驗證報告 `docs/verification/`：ERC/DRC/parity、SPICE（ngspice）、PCB 計算器（IPC-2221）、熱分析、EMC 預檢、3D／STEP、kicadiff、Jobset。
- PCB：新增 GND 縫合過孔（3mm 格點 88 顆＋訊號過孔旁 3 顆，移除孔距過近 1 顆）。DRC 仍為 0。
- 自訂零件 3D 模型（`hardware/lib/WOOW.3dshapes/`，`scripts/make_3d_models.py`）。
- `.kicad_jobset`：KiCad 原生一鍵產出，8/8 成功。
- `.kicad_pro` MAINS 類別間距 2.5mm → 1.5mm，與 `.kicad_dru` 一致。
- CI：新增 SPICE 模擬（繼電器關斷尖峰 < 20V 才通過）與 STEP 輸出。
- 新增標籤 `v1.3`（含 V1.3 PCB；`v1.3-baseline` 只有原理圖）。
- **發現**：市電 1.5mm 走線在 1oz 銅剛好等於保險絲 3.15A，負載 >3A 須改 2oz 銅。

## [2.0] — 安規改版

**檢查結果**：KiCad ERC 0 錯誤；DRC 0 錯誤、0 未連線、原理圖與 PCB 一致（含市電安規規則）。

### 電路
- 新增 F1 慢斷保險絲 T3.15A（AC_L 入口，同時保護 IRM 電源與 P3 輸出到風扇的迴路）。
- 新增 RV1 壓敏電阻 07D471K（L-N 突波）。
- U4：LM1117 線性穩壓 → AP63203WU 同步降壓（L2 3.9µH、C7/C13 22µF、C12 BST 100nF，依規格書 Table 2）。12V 側預算 ~146mA，低於 IRM-02-12 額定 167mA。
- ZS3L 串口接到 STM32 USART1（TXD→PA10、RXD←PA9）、RST←PB1（R13 10k 上拉）；指示燈改由 PB0 控制。
- NRST 電容 1µF → 100nF；VDDA 新增 C10 1µF；BOOT0 新增測試點 TP1。
- IRM 的 AC 兩腳 L/N 對調（佈線需要，IRM 輸入不分極性）。

### PCB
- 市電 ↔ 低壓：全板 ≥ 6.4mm（原 0.127mm）。GND 鋪銅由 DRC 規則自動退讓。
- 市電不同網路之間 ≥ 1.5mm（IEC 60664-1 功能絕緣；G5Q 相鄰接點腳本身約 1.67mm）。
- 銅到板邊 ≥ 0.5mm（原 0.26mm）。
- 固定孔到市電銅箔 ≥ 2.3mm（新 DRC 規則 `hole_to_mains`）：右緣市電走道外移到 x=30.2mm、AC_N 在 H2 旁內彎；H2 0.85→2.85mm、H4 1.90→2.90mm。仍須用尼龍螺絲。
- 繼電器驅動元件（D/Q/R）移到線圈腳旁、離市電 6.4mm 以外；RF1、P2、S1（改背面）、降壓電路重新擺放。
- 新增固定孔 H1–H4（M3，非金屬化，位置不變）。
- 繼電器改用收緊 courtyard 的 `WOOW:Relay_SPDT_Omron-G5Q-1_Tight`（原板間距 10.67mm、本體 10.0mm）。
- LCSC 料號不印在絲印上。

### 工具
- `scripts/build_v20.sh` 一鍵重建：原 Gerber → V2.0 擺件 → 市電格點佈線（`mains_router.py`）→ Freerouting 低壓佈線（`route_v20.py`）→ 補線（`route_leftovers.py`）→ 鋪銅 → DRC。
- `.github/workflows/kicad-ci.yml`：每次 push / PR 跑 ERC、DRC、產生 Gerber／鑽孔／座標／BOM／PDF。

## [1.3] — 原設計重繪（基準線）
- 依原設計 V1.3（Altium，2025-08-28 PDF 原理圖）在 KiCad 10 重繪原理圖，電路**完全不變**，作為改版比對基準。
- 位號對照：原 `Relay1–Relay4` → `K1–K4`（KiCad 慣例）。
- 自訂封裝（`hardware/lib/WOOW.pretty`）焊盤座標量測自原 Gerber。
- 新增 V1.3 PCB：`scripts/import_v13_pcb.py` 把原 Gerber 銅箔（走線、過孔）轉成 KiCad，零件以焊盤對齊放回原位，鋪銅照原設計 0.127mm。
  - 原理圖 vs 銅箔：0 個網路衝突、schematic parity 0 → 重繪原理圖已被實際銅箔驗證。
  - 修正：S1 指撥開關 1/2 對應 Mode_bit1/Mode_bit0（依銅箔）。
- 新增安規 DRC 規則 `WO30109_FreshAir.kicad_dru`：市電↔低壓 6.4mm、市電網路間 2.5mm、銅到板邊 0.5mm。
  - V1.3 跑出 253 個市電↔低壓違規、15 個市電網路間違規（原設計全板只用 0.127mm 間距）。

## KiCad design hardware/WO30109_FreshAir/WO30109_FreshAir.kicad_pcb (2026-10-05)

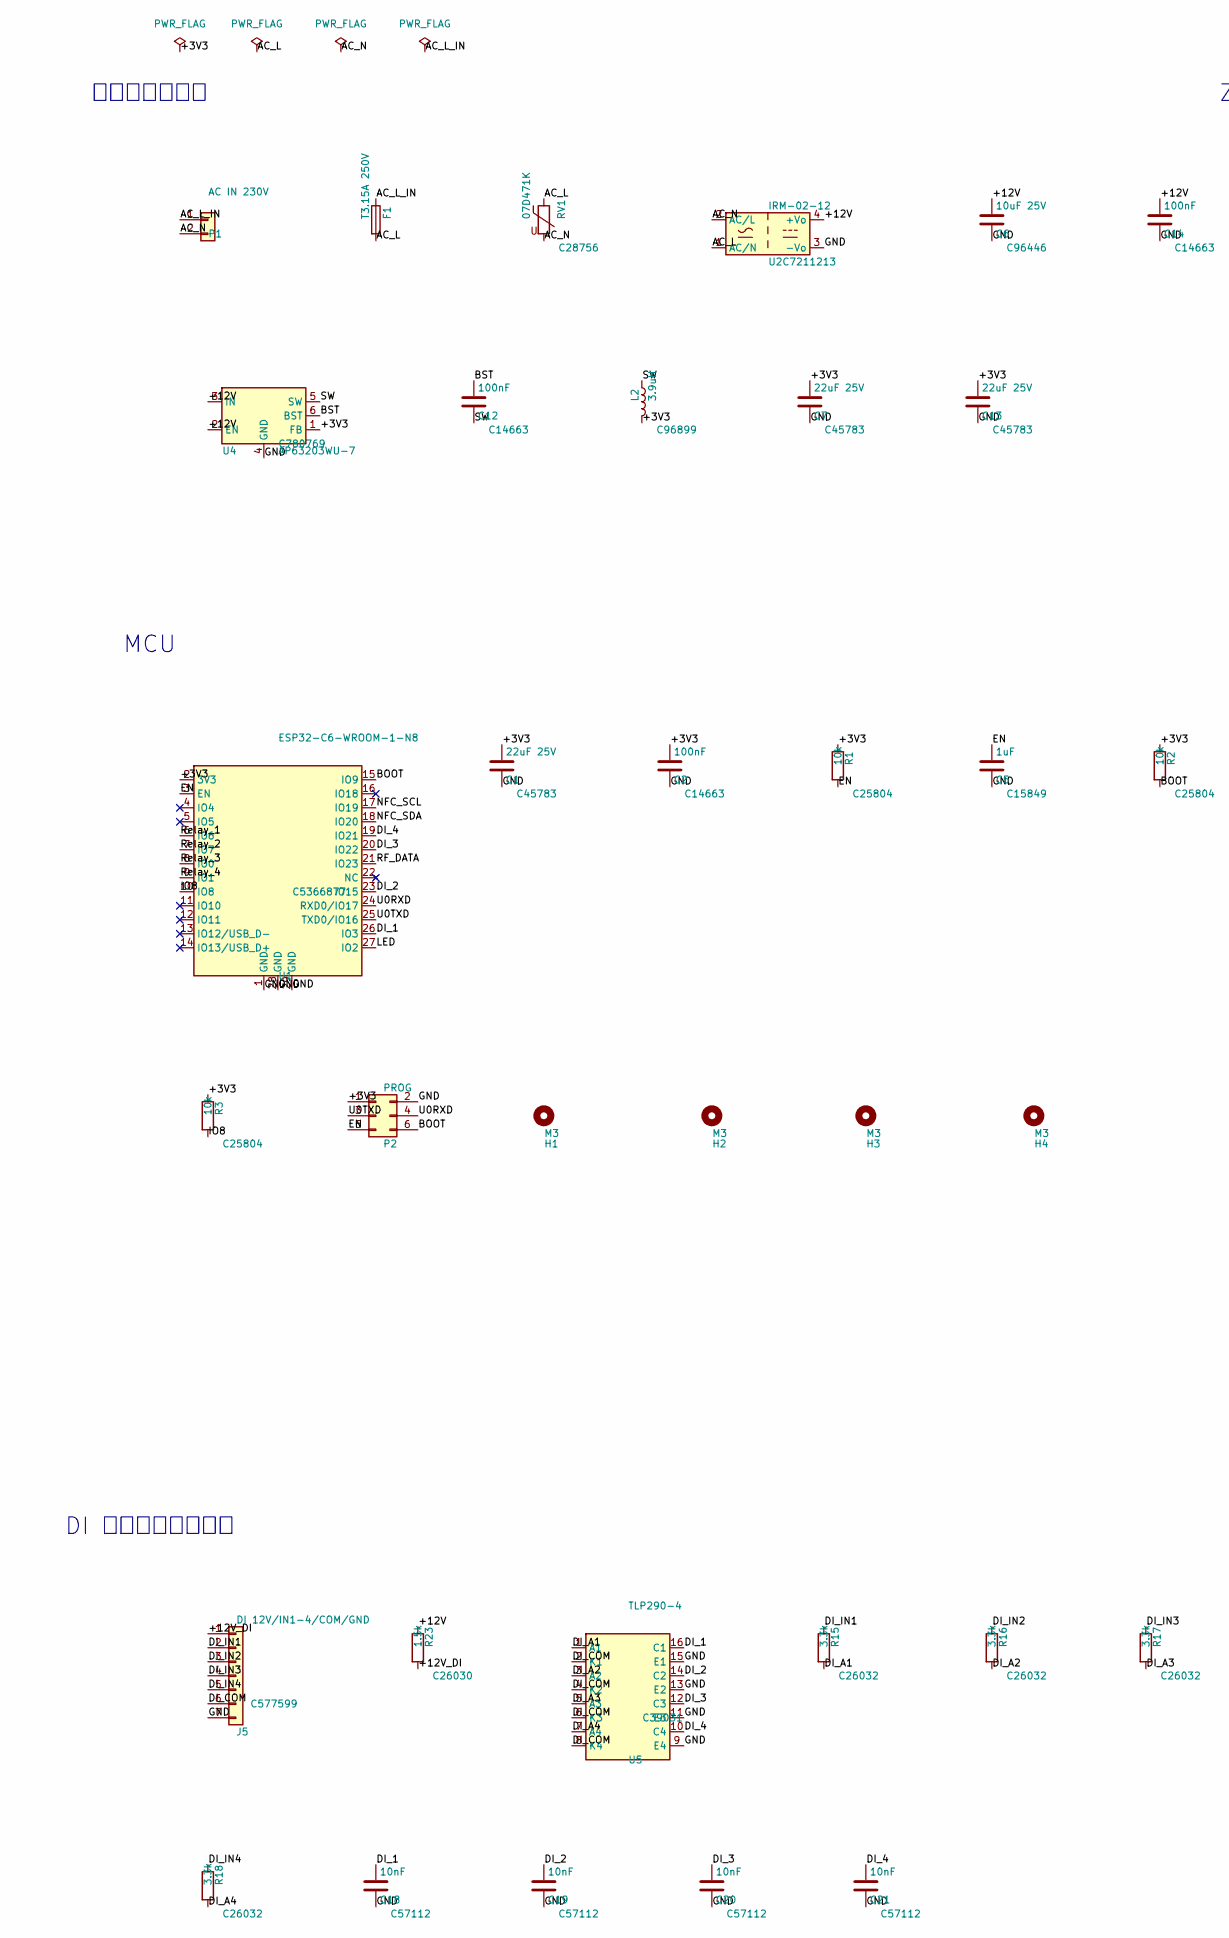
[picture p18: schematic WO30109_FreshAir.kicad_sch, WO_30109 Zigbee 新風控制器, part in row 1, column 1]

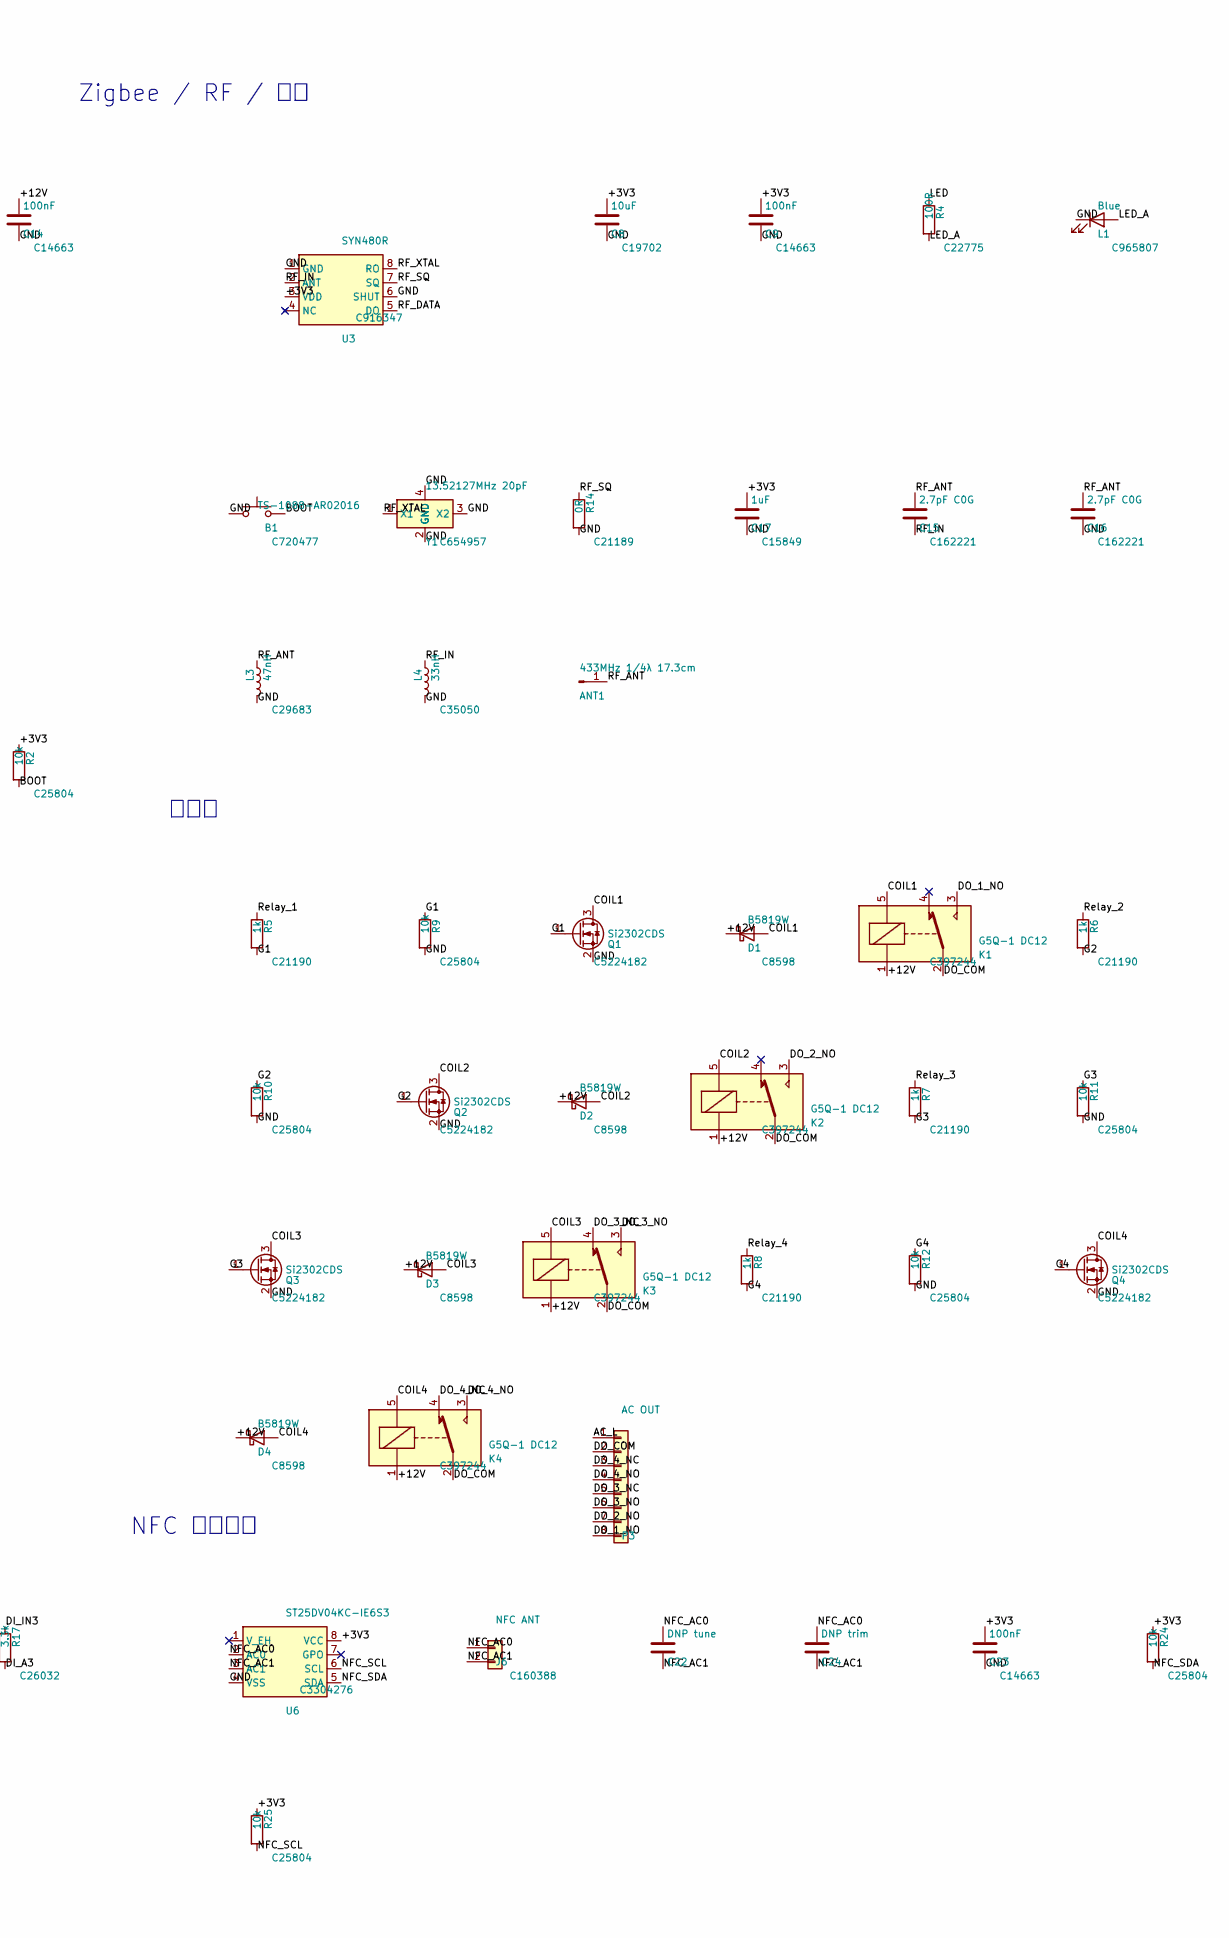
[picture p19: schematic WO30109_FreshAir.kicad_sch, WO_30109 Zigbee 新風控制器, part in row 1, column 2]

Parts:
ANT1: 433MHz 1/4λ 17.3cm; TestPoint_THTPad_D2.0mm_Drill1.0mm
B1: TS-1088-AR02016; SW_SPST_TS-1088; LCSC C720477
C1, C7, C13: 22uF 25V; C_0805_2012Metric; LCSC C45783
C2, C9, C12, C14, C23: 100nF; C_0603_1608Metric; LCSC C14663
C5, C17: 1uF; C_0603_1608Metric; LCSC C15849
C6: 10uF 25V; C_0603_1608Metric; LCSC C96446
C8: 10uF; C_0603_1608Metric; LCSC C19702
C15, C16: 2.7pF C0G; C_0603_1608Metric; LCSC C162221
C18, C19, C20, C21: 10nF; C_0603_1608Metric; LCSC C57112
C22: DNP tune; C_0603_1608Metric
C24: DNP trim; C_0603_1608Metric
D1, D2, D3, D4: B5819W; D_SOD-123; LCSC C8598
F1: T3.15A 250V; Fuseholder_TR5_Littelfuse_No560_No460
H1, H2, H3, H4: M3; MountingHole_3.2mm_M3
J5: DI 12V/IN1-4/COM/GND; TerminalBlock_Pluggable_1x07_P2.54mm_Horizontal; LCSC C577599
J6: NFC ANT; JST_SH_BM02B-SRSS-TB_1x02-1MP_P1.00mm_Vertical; LCSC C160388
K1, K2, K3, K4: G5Q-1 DC12; Relay_SPDT_Omron-G5Q-1_Tight; LCSC C397244
L1: Blue; LED_0603_1608Metric; LCSC C965807
L2: 3.9uH; L_Sunlord_SWPA4030S; LCSC C96899
L3: 47nH; L_0603_1608Metric; LCSC C29683
L4: 33nH; L_0603_1608Metric; LCSC C35050
P1: AC IN 230V; TerminalBlock_Pluggable_1x02_P5.00mm_Horizontal
P2: PROG; ProgPads_2x03_P2.54mm
P3: AC OUT; TerminalBlock_Pluggable_1x08_P5.08mm_Horizontal
Q1, Q2, Q3, Q4: Si2302CDS; SOT-23; LCSC C5224182
R1, R2, R3, R9, R10, R11, R12, R24, R25: 10k; R_0603_1608Metric; LCSC C25804
R4: 100R; R_0603_1608Metric; LCSC C22775
R5, R6, R7, R8: 1k; R_0603_1608Metric; LCSC C21190
R14: 0R; R_0603_1608Metric; LCSC C21189
R15, R16, R17, R18: 3.3k; R_1206_3216Metric; LCSC C26032
R23: 1.5k; R_1206_3216Metric; LCSC C26030
RV1: 07D471K; RV_Disc_D7mm_W3.4mm_P5mm; LCSC C28756
U1: ESP32-C6-WROOM-1-N8; Espressif_ESP32-C6-WROOM-1; LCSC C5366877
U2: IRM-02-12; Converter_ACDC_MeanWell_IRM-02-xx_THT; LCSC C7211213
U3: SYN480R; SOIC-8_3.9x4.9mm_P1.27mm; LCSC C916347
U4: AP63203WU-7; TSOT-23-6; LCSC C780769
U5: TLP290-4; SOP-16_4.55x10.3mm_P1.27mm; LCSC C39031
U6: ST25DV04KC-IE6S3; SOIC-8_3.9x4.9mm_P1.27mm; LCSC C3304276
Y1: 13.52127MHz 20pF; Crystal_SMD_3225-4Pin_3.2x2.5mm; LCSC C654957

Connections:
/+3V3: C1.1, C2.1, C7.1, C8.1, C9.1, C13.1, C17.1, C23.1, L2.2, P2.1, R1.1, R2.1, R3.1, R24.1, R25.1, U1.2 (3V3), U3.3 (VDD), U4.1 (FB), U6.8 (VCC)
/+12V: C6.1, C14.1, D1.1 (K), D2.1 (K), D3.1 (K), D4.1 (K), K1.1, K2.1, K3.1, K4.1, R23.1, U2.4 (+Vo), U4.2 (EN), U4.3 (IN)
/+12V_DI: J5.1, R23.2
/AC_L: F1.2, P3.1, RV1.1, U2.1 (AC/N)
/AC_L_IN: F1.1, P1.1
/AC_N: P1.2, RV1.2, U2.2 (AC/L)
/BOOT: B1.2, P2.6, R2.2, U1.15 (IO9)
/BST: C12.1, U4.6 (BST)
/COIL1: D1.2 (A), K1.5, Q1.3 (D)
/COIL2: D2.2 (A), K2.5, Q2.3 (D)
/COIL3: D3.2 (A), K3.5, Q3.3 (D)
/COIL4: D4.2 (A), K4.5, Q4.3 (D)
/DI_1: C18.1, U1.26 (IO3), U5.16 (C1)
/DI_2: C19.1, U1.23 (IO15), U5.14 (C2)
/DI_3: C20.1, U1.20 (IO22), U5.12 (C3)
/DI_4: C21.1, U1.19 (IO21), U5.10 (C4)
/DI_A1: R15.2, U5.1 (A1)
/DI_A2: R16.2, U5.3 (A2)
/DI_A3: R17.2, U5.5 (A3)
/DI_A4: R18.2, U5.7 (A4)
/DI_COM: J5.6, U5.2 (K1), U5.4 (K2), U5.6 (K3), U5.8 (K4)
/DI_IN1: J5.2, R15.1
/DI_IN2: J5.3, R16.1
/DI_IN3: J5.4, R17.1
/DI_IN4: J5.5, R18.1
/DO_1_NO: K1.3, P3.8
/DO_2_NO: K2.3, P3.7
/DO_3_NC: K3.4, P3.5
/DO_3_NO: K3.3, P3.6
/DO_4_NC: K4.4, P3.3
/DO_4_NO: K4.3, P3.4
/DO_COM: K1.2, K2.2, K3.2, K4.2, P3.2
/EN: C5.1, P2.5, R1.2, U1.3 (EN)
/G1: Q1.1 (G), R5.2, R9.1
/G2: Q2.1 (G), R6.2, R10.1
/G3: Q3.1 (G), R7.2, R11.1
/G4: Q4.1 (G), R8.2, R12.1
/GND: B1.1, C1.2, C2.2, C5.2, C6.2, C7.2, C8.2, C9.2, C13.2, C14.2, C16.2, C17.2, C18.2, C19.2, C20.2, C21.2, C23.2, J5.7, L1.1 (K), L3.2, L4.2, P2.2, Q1.2 (S), Q2.2 (S), Q3.2 (S), Q4.2 (S), R9.2, R10.2, R11.2, R12.2, R14.2, U1.1 (GND), U1.28 (GND), U1.29 (GND), U2.3 (-Vo), U3.1 (GND), U3.6 (SHUT), U4.4 (GND), U5.9 (E4), U5.11 (E3), U5.13 (E2), U5.15 (E1), U6.4 (VSS), Y1.2 (GND), Y1.3 (X2), Y1.4 (GND)
/IO8: R3.2, U1.10 (IO8)
/LED: R4.1, U1.27 (IO2)
/LED_A: L1.2 (A), R4.2
/NFC_AC0: C22.1, C24.1, J6.1, U6.2 (AC0)
/NFC_AC1: C22.2, C24.2, J6.2, U6.3 (AC1)
/NFC_SCL: R25.2, U1.17 (IO19), U6.6 (SCL)
/NFC_SDA: R24.2, U1.18 (IO20), U6.5 (SDA)
/RF_ANT: ANT1.1, C15.1, C16.1, L3.1
/RF_DATA: U1.21 (IO23), U3.5 (DO)
/RF_IN: C15.2, L4.1, U3.2 (ANT)
/RF_SQ: R14.1, U3.7 (SQ)
/RF_XTAL: U3.8 (RO), Y1.1 (X1)
/Relay_1: R5.1, U1.6 (IO6)
/Relay_2: R6.1, U1.7 (IO7)
/Relay_3: R7.1, U1.8 (IO0)
/Relay_4: R8.1, U1.9 (IO1)
/SW: C12.2, L2.1, U4.5 (SW)
/U0RXD: P2.4, U1.24 (RXD0/IO17)
/U0TXD: P2.3, U1.25 (TXD0/IO16)

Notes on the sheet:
市電輸入／電源
MCU
Zigbee / RF / 介面
繼電器
DI 輸入（光耦隔離）
NFC 設定介面

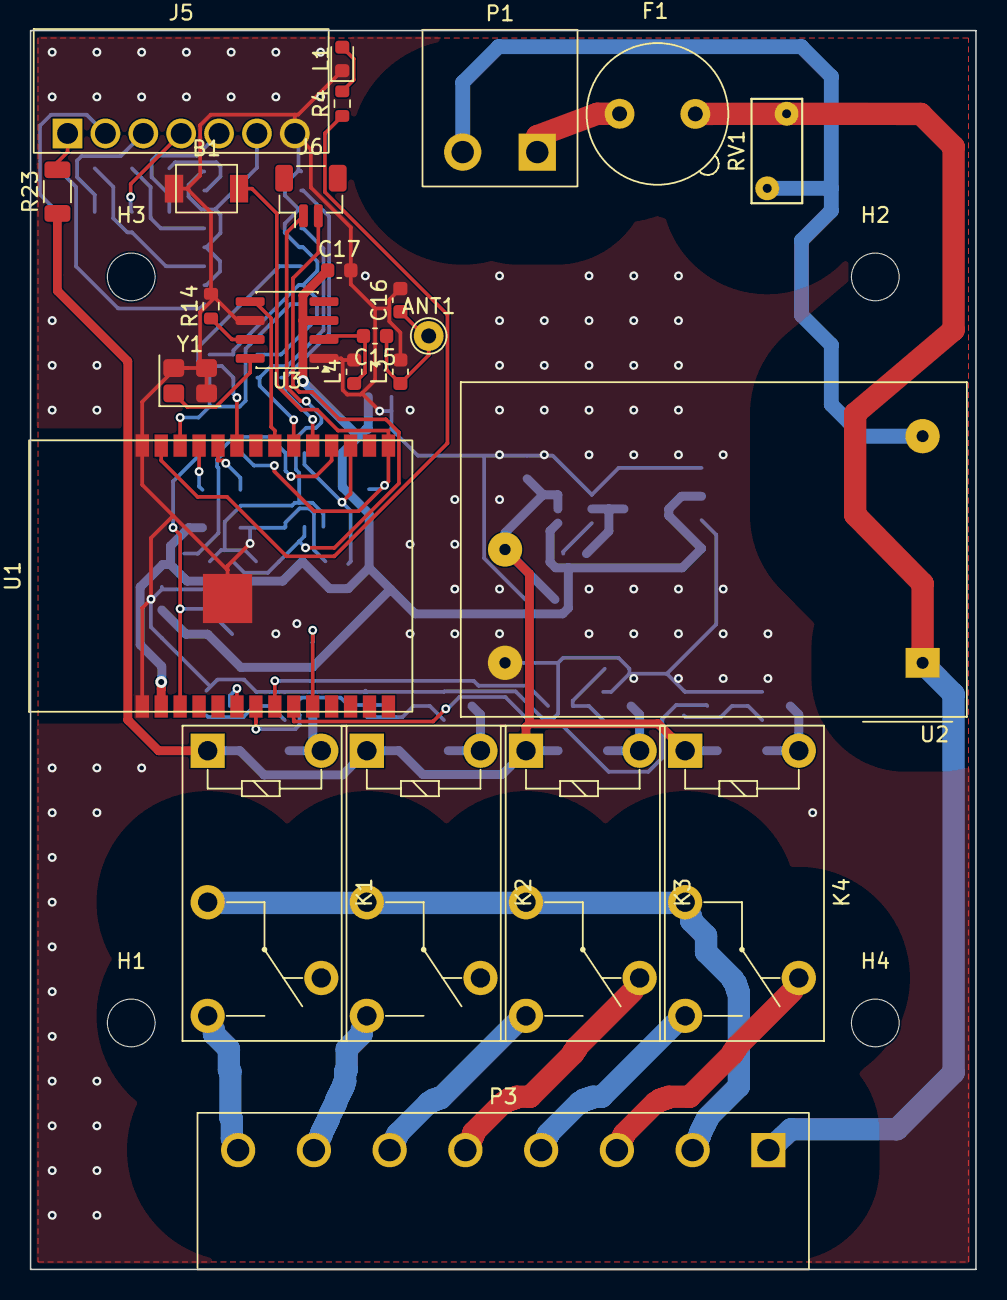
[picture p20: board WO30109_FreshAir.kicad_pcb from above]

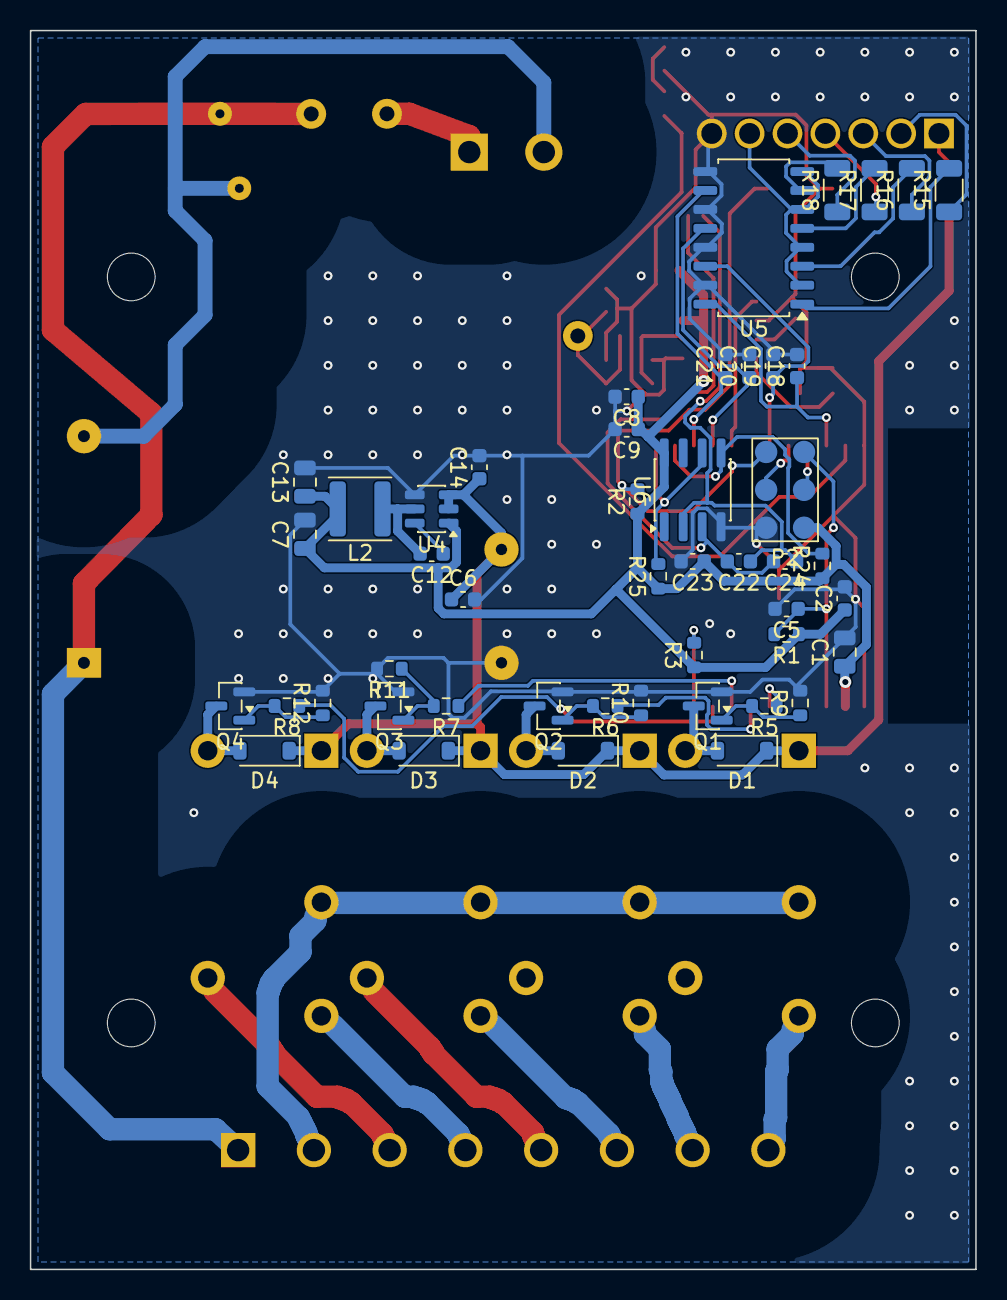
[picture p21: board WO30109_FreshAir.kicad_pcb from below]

Board: 2 copper layers, 63.4 x 83.1 mm, 76 parts (47 on the bottom side), 57 nets.

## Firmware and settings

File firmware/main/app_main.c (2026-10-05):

/* WO_30109 新風控制器 V3.0 主程式：硬體（GPIO／中斷／NVS）接到 fa_core 純邏輯與 Zigbee。
 *
 * 執行緒
 *   relay_task   依動作清單切繼電器（先斷後通、吸合錯開），完成後同步 Zigbee 屬性
 *   rf_task      SYN480R DO 腳邊緣中斷 → 脈寬 → EV1527 解碼 → 學習／控制
 *   ui_task      每 10ms 掃按鍵、更新燈號
 *   zigbee       見 fa_zigbee.c
 */
#include <string.h>

#include "driver/gpio.h"
#include "driver/ledc.h"
#include "esp_log.h"
#include "esp_timer.h"
#include "freertos/FreeRTOS.h"
#include "freertos/queue.h"
#include "freertos/semphr.h"
#include "freertos/task.h"
#include "nvs.h"
#include "nvs_flash.h"

#include "board.h"
#include "fa_button.h"
#include "fa_coil.h"
#include "fa_ev1527.h"
#include "fa_io.h"
#include "fa_nfc_port.h"
#include "fa_relays.h"
#include "fa_remotes.h"
#include "fa_zigbee.h"

static const char *TAG = "fa";

static const gpio_num_t RELAY_PIN[FA_CH] = {PIN_RELAY_1, PIN_RELAY_2, PIN_RELAY_3, PIN_RELAY_4};
static const gpio_num_t DI_PIN[FA_CH] = {PIN_DI_1, PIN_DI_2, PIN_DI_3, PIN_DI_4};

static fa_relays_t       s_relays;
static fa_remotes_t      s_remotes;
static fa_io_t           s_io;             /* DI／DO 模式與狀態（V3.2） */
static SemaphoreHandle_t s_lock;           /* 保護 s_relays / s_remotes / s_io */
static QueueHandle_t     s_relay_q;        /* fa_action_t；ch = 0xFF 表示「這批結束，請同步」 */
static QueueHandle_t     s_rf_q;           /* rf_edge_t */
static volatile int64_t  s_learn_until_us; /* 學習模式到期時間；0 = 關 */
static volatile int64_t  s_identify_until_us; /* NFC「找裝置」：LED 快閃到期時間 */
static char              s_name[FA_NFC_NAME_LEN] = "WO30109";   /* 裝置名稱（NFC App 設定，存 NVS） */

static uint32_t now_ms(void) { return (uint32_t)(esp_timer_get_time() / 1000); }

/* ---------------- 繼電器 ---------------- */
#define SYNC_MARK 0xFF

/* n > 0：執行動作後同步；n < 0（被拒絕）：只同步，把 Zigbee 屬性打回實際狀態；
 * n == 0（狀態沒變）：什麼都不送——否則本地同步屬性若又觸發寫入回呼，會無限循環 */
static void post_actions(const fa_action_t *a, int n)
{
    if (n == 0) return;
    for (int i = 0; i < n; i++) xQueueSend(s_relay_q, &a[i], portMAX_DELAY);
    fa_action_t mark = {.ch = SYNC_MARK};
    xQueueSend(s_relay_q, &mark, portMAX_DELAY);
}

/* 對 s_relays 做一次無參數操作（循環、全關）並送出動作 */
static int apply(int (*op)(fa_relays_t *r, fa_action_t *out, int max))
{
    fa_action_t a[8];
    xSemaphoreTake(s_lock, portMAX_DELAY);
    int n = op(&s_relays, a, 8);
    xSemaphoreGive(s_lock);
    post_actions(a, n);
    return n;
}

static int relay_set(uint8_t ch, bool on)
{
    fa_action_t a[8];
    xSemaphoreTake(s_lock, portMAX_DELAY);
    int n = fa_relays_set(&s_relays, ch, on, a, 8);
    xSemaphoreGive(s_lock);
    post_actions(a, n);
    if (n == FA_ERR_LIMIT) ESP_LOGW(TAG, "繼電器 %d：已達同時吸合上限 %d", ch + 1, CONFIG_FA_MAX_RELAYS_ON);
    return n;
}

/* ---------------- DI／DO（V3.2）：接線 DI 與遙控器 4 鍵 ---------------- */
static void io_post(int n, uint8_t ch)
{
    if (n == FA_ERR_LIMIT) ESP_LOGW(TAG, "DI%d：已達同時吸合上限 %d", ch + 1, CONFIG_FA_MAX_RELAYS_ON);
}

static void io_cfg_default(fa_io_cfg_t *c)
{
#if CONFIG_FA_PRESET_FAN2
    fa_io_default(c, FA_MODE_FAN2);
#elif CONFIG_FA_PRESET_4CH
    fa_io_default(c, FA_MODE_4CH);
#elif CONFIG_FA_PRESET_SEL4
    fa_io_default(c, FA_MODE_SEL4);
#else
    fa_io_default(c, FA_MODE_FAN3);
#endif
    for (int k = 0; k < FA_CH; k++) {
#if CONFIG_FA_DI_DEFAULT_PRESS
        c->di_mode[k] = FA_DI_PRESS;
#elif CONFIG_FA_DI_DEFAULT_OFF
        c->di_mode[k] = FA_DI_OFF;
#endif
        c->jog_ms[k] = CONFIG_FA_JOG_MS;
    }
}

/* 設定存 NVS（"fa"/"io_cfg"）；讀不到或內容不合法就用出廠預設。V4（Matter）由 HA／維護網頁寫入 */
static void io_cfg_load(fa_io_cfg_t *c)
{
    nvs_handle_t h;
    size_t len = sizeof *c;
    bool ok = false;
    if (nvs_open("fa", NVS_READONLY, &h) == ESP_OK) {
        ok = nvs_get_blob(h, "io_cfg", c, &len) == ESP_OK && len == sizeof *c && fa_io_cfg_valid(c);
        nvs_close(h);
    }
    if (!ok) io_cfg_default(c);
}

#if !CONFIG_FA_BOARD_V32                           /* 只有 NFC 會改 DI／DO 設定（V4 Matter 起 HA 也會） */
static void io_cfg_save(const fa_io_cfg_t *c)
{
    nvs_handle_t h;
    if (nvs_open("fa", NVS_READWRITE, &h) != ESP_OK) return;
    nvs_set_blob(h, "io_cfg", c, sizeof *c);
    nvs_commit(h);
    nvs_close(h);
}
#endif

static void name_load_save(bool save)
{
    nvs_handle_t h;
    size_t len = sizeof s_name;
    if (nvs_open("fa", save ? NVS_READWRITE : NVS_READONLY, &h) != ESP_OK) return;
    if (save) { nvs_set_str(h, "name", s_name); nvs_commit(h); }
    else if (nvs_get_str(h, "name", s_name, &len) != ESP_OK) strcpy(s_name, "WO30109");
    nvs_close(h);
}

static void io_cfg_erase(void)
{
    nvs_handle_t h;
    if (nvs_open("fa", NVS_READWRITE, &h) != ESP_OK) return;
    nvs_erase_key(h, "io_cfg");
    nvs_commit(h);
    nvs_close(h);
}

/* ---------------- 線圈驅動：全壓吸合 → PWM 降壓保持 ---------------- */
/* 電源預算的前提（fa_coil.h、Kconfig help）。menuconfig 改過其中一項，另一項不會跟著變，所以在這裡擋。 */
#if !CONFIG_FA_RELAY_PWM_HOLD && CONFIG_FA_MAX_RELAYS_ON > 3
#error "全壓驅動 4 顆＋發射峰值約 191mA，超過 IRM-02-12 保護點：關掉 FA_RELAY_PWM_HOLD 時 FA_MAX_RELAYS_ON 要 ≤3"
#endif
#if CONFIG_FA_RELAY_PWM_HOLD && CONFIG_FA_RELAY_STAGGER_MS <= CONFIG_FA_RELAY_PULLIN_MS
#error "FA_RELAY_STAGGER_MS 要大於 FA_RELAY_PULLIN_MS，才能保證同時最多 1 顆在全壓吸合"
#endif
#if CONFIG_FA_RELAY_PWM_HOLD
#define COIL_RES  LEDC_TIMER_10_BIT
#define COIL_FULL (1u << 10)                   /* LEDC duty = 2^res → 恆高 */
static const fa_coil_cfg_t COIL_CFG = {.pullin_ms = CONFIG_FA_RELAY_PULLIN_MS, .hold_pct = CONFIG_FA_RELAY_HOLD_PCT,
                                       .supply_mv = 12000, .coil_ohm = 360, .diode_mv = 300};
static esp_timer_handle_t s_hold_timer[FA_CH];
static bool               s_coil_on[FA_CH];
static SemaphoreHandle_t  s_coil_lock;        /* 保持計時器回呼與 coil_set 互斥，避免「剛關掉又被設成保持」 */

static void coil_write(uint8_t ch, uint8_t pct)
{
    ledc_set_duty(LEDC_LOW_SPEED_MODE, (ledc_channel_t)ch, pct >= 100 ? COIL_FULL : COIL_FULL * pct / 100);
    ledc_update_duty(LEDC_LOW_SPEED_MODE, (ledc_channel_t)ch);
}

static void coil_hold_cb(void *arg)
{
    uint8_t ch = (uint8_t)(uintptr_t)arg;
    xSemaphoreTake(s_coil_lock, portMAX_DELAY);
    if (s_coil_on[ch]) coil_write(ch, fa_coil_duty_pct(&COIL_CFG, true, COIL_CFG.pullin_ms));
    xSemaphoreGive(s_coil_lock);
}

static void coil_init(void)
{
    s_coil_lock = xSemaphoreCreateMutex();
    ledc_timer_config_t t = {.speed_mode = LEDC_LOW_SPEED_MODE, .duty_resolution = COIL_RES,
                             .timer_num = LEDC_TIMER_0, .freq_hz = CONFIG_FA_RELAY_PWM_HZ, .clk_cfg = LEDC_AUTO_CLK};
    ESP_ERROR_CHECK(ledc_timer_config(&t));
    for (int i = 0; i < FA_CH; i++) {
        ledc_channel_config_t c = {.gpio_num = RELAY_PIN[i], .speed_mode = LEDC_LOW_SPEED_MODE,
                                   .channel = (ledc_channel_t)i, .timer_sel = LEDC_TIMER_0, .duty = 0};
        ESP_ERROR_CHECK(ledc_channel_config(&c));
        esp_timer_create_args_t a = {.callback = coil_hold_cb, .arg = (void *)(uintptr_t)i, .name = "coil_hold"};
        ESP_ERROR_CHECK(esp_timer_create(&a, &s_hold_timer[i]));
    }
    ESP_LOGI(TAG, "線圈：全壓 %dms → %d%% @ %dHz；保持時 %lumV、12V 端每顆 %lu.%01lumA",
             CONFIG_FA_RELAY_PULLIN_MS, CONFIG_FA_RELAY_HOLD_PCT, CONFIG_FA_RELAY_PWM_HZ,
             (unsigned long)fa_coil_voltage_mv(&COIL_CFG, COIL_CFG.hold_pct),
             (unsigned long)(fa_coil_supply_ua(&COIL_CFG, COIL_CFG.hold_pct) / 1000),
             (unsigned long)(fa_coil_supply_ua(&COIL_CFG, COIL_CFG.hold_pct) % 1000 / 100));
}

static void coil_set(uint8_t ch, bool on)
{
    esp_timer_stop(s_hold_timer[ch]);          /* 沒在跑會回 ESP_ERR_INVALID_STATE，忽略 */
    xSemaphoreTake(s_coil_lock, portMAX_DELAY);
    s_coil_on[ch] = on;
    coil_write(ch, fa_coil_duty_pct(&COIL_CFG, on, 0));
    xSemaphoreGive(s_coil_lock);
    if (on) esp_timer_start_once(s_hold_timer[ch], COIL_CFG.pullin_ms * 1000ULL);
}
#else
static void coil_init(void) {}
static void coil_set(uint8_t ch, bool on) { gpio_set_level(RELAY_PIN[ch], on); }
#endif

static void relay_task(void *arg)
{
    int64_t last_on_us = 0;
    fa_action_t a;
    for (;;) {
        xQueueReceive(s_relay_q, &a, portMAX_DELAY);
        if (a.ch == SYNC_MARK) {
            bool on[FA_CH];
            xSemaphoreTake(s_lock, portMAX_DELAY);
            memcpy(on, s_relays.on, sizeof on);
            xSemaphoreGive(s_lock);
            fa_zigbee_sync(on);
            continue;
        }
        if (a.delay_ms) vTaskDelay(pdMS_TO_TICKS(a.delay_ms));
        if (a.on) {                            /* 兩顆線圈吸合錯開，避免 12V 電源同時吃兩個湧浪 */
            int64_t wait_us = last_on_us + CONFIG_FA_RELAY_STAGGER_MS * 1000LL - esp_timer_get_time();
            if (wait_us > 0) vTaskDelay(pdMS_TO_TICKS(wait_us / 1000 + 1));
            last_on_us = esp_timer_get_time();
        }
        coil_set(a.ch, a.on);
        ESP_LOGI(TAG, "繼電器 %d %s", a.ch + 1, a.on ? "ON" : "OFF");
    }
}

static bool zb_on_set(uint8_t ch, bool on)
{
    int n = relay_set(ch, on);
    return n >= 0;
}

/* ---------------- 遙控器學習表（NVS） ---------------- */
static void remotes_load(void)
{
    nvs_handle_t h;
    size_t len = sizeof s_remotes;
    fa_remotes_init(&s_remotes);
    if (nvs_open("fa", NVS_READONLY, &h) == ESP_OK) {
        if (nvs_get_blob(h, "remotes", &s_remotes, &len) != ESP_OK || len != sizeof s_remotes || s_remotes.n > FA_REMOTES_MAX)
            fa_remotes_init(&s_remotes);
        nvs_close(h);
    }
    ESP_LOGI(TAG, "已學習遙控器 %d 支", s_remotes.n);
}

static void remotes_save(void)
{
    nvs_handle_t h;
    if (nvs_open("fa", NVS_READWRITE, &h) != ESP_OK) return;
    nvs_set_blob(h, "remotes", &s_remotes, sizeof s_remotes);
    nvs_commit(h);
    nvs_close(h);
}

/* ---------------- 433MHz：邊緣中斷 → 解碼 ---------------- */
typedef struct {
    uint32_t dur_us;
    uint8_t  level;     /* 這段持續的電位（邊緣之前） */
} rf_edge_t;

static void IRAM_ATTR rf_isr(void *arg)
{
    static int64_t last;
    int64_t t = esp_timer_get_time();
    rf_edge_t e = {.dur_us = (uint32_t)(t - last), .level = !gpio_get_level(PIN_RF_DATA)};
    last = t;
    BaseType_t woken = pdFALSE;
    xQueueSendFromISR(s_rf_q, &e, &woken);   /* 佇列滿就丟（只會是雜訊暴量） */
    if (woken) portYIELD_FROM_ISR();
}

static void rf_task(void *arg)
{
    fa_ev1527_t dec;
    fa_ev1527_init(&dec);
    uint32_t last_code = 0, last_ms = 0;
    rf_edge_t e;
    for (;;) {
        xQueueReceive(s_rf_q, &e, portMAX_DELAY);
        uint32_t code;
        if (!fa_ev1527_feed(&dec, e.level, e.dur_us, &code)) continue;
        uint32_t t = now_ms();
        uint32_t addr = fa_ev1527_addr(code);
        uint8_t  key = fa_ev1527_key(code);
        bool repeat = code == last_code && t - last_ms < 600;          /* 同一次按壓的重送 */
        last_code = code;
        last_ms = t;
        if (!repeat) ESP_LOGI(TAG, "433：位址 0x%05lx 鍵 0x%x", (unsigned long)addr, key);

        if (s_learn_until_us && esp_timer_get_time() < s_learn_until_us) {
            if (repeat) continue;
            xSemaphoreTake(s_lock, portMAX_DELAY);
            fa_remotes_add(&s_remotes, addr);
            xSemaphoreGive(s_lock);
            remotes_save();
            s_learn_until_us = 0;
            fa_nfc_port_publish();
            ESP_LOGI(TAG, "學習完成：0x%05lx（共 %d 支）", (unsigned long)addr, s_remotes.n);
            continue;
        }
        /* 遙控器第 k 鍵＝DI k 的分身：每一幀都送進去（按住判定靠持續收到幀，放開由 fa_io_tick 逾時判定） */
        int ch = fa_remote_key_to_channel(key);
        fa_action_t a[8];
        xSemaphoreTake(s_lock, portMAX_DELAY);
        bool known = fa_remotes_has(&s_remotes, addr);
        int n = (known && ch >= 0) ? fa_io_rf(&s_io, &s_relays, (uint8_t)ch, t, a, 8) : 0;
        xSemaphoreGive(s_lock);
        post_actions(a, n);
        io_post(n, (uint8_t)ch);
    }
}

/* ---------------- NFC 設定介面（V3.3）的 callback ---------------- */
#if !CONFIG_FA_BOARD_V32
static void nfc_get_cfg(fa_nfc_cfg_t *c)
{
    memset(c, 0, sizeof *c);
    xSemaphoreTake(s_lock, portMAX_DELAY);
    c->io = s_io.cfg;
    memcpy(c->name, s_name, sizeof c->name);
    c->n_remotes = s_remotes.n > FA_NFC_REMOTES_MAX ? FA_NFC_REMOTES_MAX : s_remotes.n;
    for (int i = 0; i < c->n_remotes; i++) c->remotes[i] = s_remotes.addr[i];
    xSemaphoreGive(s_lock);
}

/* 套用 App 送來（已驗簽）的設定。互鎖分組變了就先全關再重新分組，避免新組合下出現不該同時吸合的狀態 */
static void nfc_apply_cfg(const fa_nfc_cfg_t *c)
{
    fa_action_t a[8];
    int n = 0;
    xSemaphoreTake(s_lock, portMAX_DELAY);
    uint8_t old_mask = fa_io_interlock_mask(&s_io.cfg), new_mask = fa_io_interlock_mask(&c->io);
    if (old_mask != new_mask) {
        n = fa_relays_all_off(&s_relays, a, 8);
        fa_relays_init_group(&s_relays, new_mask, CONFIG_FA_MAX_RELAYS_ON, CONFIG_FA_INTERLOCK_DEAD_MS);
    }
    fa_io_init(&s_io, &c->io);                    /* DI 狀態重新偵測：接通中的「持續」接點會在 30ms 後重新作動 */
    fa_remotes_init(&s_remotes);
    for (int i = 0; i < c->n_remotes; i++) fa_remotes_add(&s_remotes, c->remotes[i]);
    memcpy(s_name, c->name, sizeof s_name);
    s_name[sizeof s_name - 1] = 0;
    xSemaphoreGive(s_lock);
    post_actions(a, n);
    io_cfg_save(&c->io);
    remotes_save();
    name_load_save(true);
    ESP_LOGI(TAG, "NFC 套用新設定：互鎖 0x%x、遙控器 %d 支、名稱「%s」", new_mask, c->n_remotes, s_name);
}

static void nfc_get_status(fa_nfc_status_t *st)
{
    xSemaphoreTake(s_lock, portMAX_DELAY);
    for (int k = 0; k < FA_CH; k++) {
        if (s_relays.on[k]) st->relays |= 1u << k;
        if (s_io.active[k]) st->di |= 1u << k;
    }
    xSemaphoreGive(s_lock);
    st->net = fa_zigbee_joined();
    st->flags = (s_learn_until_us && esp_timer_get_time() < s_learn_until_us) ? 1 : 0;
}

static void nfc_learn(void) { s_learn_until_us = esp_timer_get_time() + 20 * 1000000LL; }
static void nfc_identify(void) { s_identify_until_us = esp_timer_get_time() + 5 * 1000000LL; }
static void factory_reset(void);
static void nfc_factory_reset(void) { factory_reset(); }
#endif

/* ---------------- 按鍵、燈號 ---------------- */
static void factory_reset(void)
{
    ESP_LOGW(TAG, "恢復出廠：全部繼電器關、清除遙控器與 DI/DO 設定、Zigbee 離網");
    apply(fa_relays_all_off);
    xSemaphoreTake(s_lock, portMAX_DELAY);
    fa_remotes_init(&s_remotes);
    xSemaphoreGive(s_lock);
    remotes_save();
    io_cfg_erase();
    strcpy(s_name, "WO30109"); name_load_save(true);
    fa_nfc_port_publish();                         /* gen＋1：重置前 App 手上的請求全部作廢 */
    vTaskDelay(pdMS_TO_TICKS(300));
    fa_zigbee_factory_reset();
}

static bool led_pattern(uint32_t t, uint32_t held)
{
    if (held >= FA_BTN_VLONG_MIN) return true;                             /* 按住 ≥10s：恆亮＝放開就重置 */
    if (held >= FA_BTN_LONG_MIN) return (t / 100) % 2;                     /* 3–8s：快閃＝放開進學習 */
    if (s_learn_until_us && esp_timer_get_time() < s_learn_until_us) return (t / 100) % 2;
    if (s_identify_until_us && esp_timer_get_time() < s_identify_until_us) return (t / 50) % 2;   /* NFC 找裝置 */
    if (!fa_zigbee_joined()) return (t / 500) % 2;                         /* 尚未入網：慢閃 */
    return true;                                                           /* 已入網：恆亮 */
}

static void ui_task(void *arg)
{
    fa_button_t btn;
    fa_button_init(&btn);
    for (;;) {
        uint32_t t = now_ms();
        switch (fa_button_update(&btn, gpio_get_level(PIN_BUTTON) == 0, t)) {
        case FA_BTN_SHORT:
            apply(fa_relays_cycle);
            break;
        case FA_BTN_LONG:
            s_learn_until_us = esp_timer_get_time() + 20 * 1000000LL;
            ESP_LOGI(TAG, "遙控器學習模式 20 秒：請按遙控器任一鍵");
            break;
        case FA_BTN_VLONG:
            factory_reset();
            break;
        default:
            break;
        }
        for (uint8_t k = 0; k < FA_CH; k++) {                     /* 接線 DI：每 10ms 取樣，fa_io 內部防彈跳 */
            fa_action_t a[8];
            bool closed = gpio_get_level(DI_PIN[k]) == 0;
            xSemaphoreTake(s_lock, portMAX_DELAY);
            int n = fa_io_wired(&s_io, &s_relays, k, closed, t, a, 8);
            xSemaphoreGive(s_lock);
            post_actions(a, n);
            io_post(n, k);
        }
        {                                                          /* 遙控器放開判定、點動到時 */
            fa_action_t a[8];
            xSemaphoreTake(s_lock, portMAX_DELAY);
            int n = fa_io_tick(&s_io, &s_relays, t, a, 8);
            xSemaphoreGive(s_lock);
            post_actions(a, n);
        }
        gpio_set_level(PIN_LED, led_pattern(t, fa_button_held_ms(&btn, t)));
        vTaskDelay(pdMS_TO_TICKS(10));
    }
}

/* ---------------- 啟動 ---------------- */
static void gpio_setup(void)
{
    gpio_config_t out = {.mode = GPIO_MODE_OUTPUT, .pin_bit_mask = (1ULL << PIN_LED)};
    for (int i = 0; i < FA_CH; i++) out.pin_bit_mask |= 1ULL << RELAY_PIN[i];
    for (int i = 0; i < FA_CH; i++) gpio_set_level(RELAY_PIN[i], 0);
    gpio_config(&out);
    gpio_config_t in = {.mode = GPIO_MODE_INPUT, .pull_up_en = GPIO_PULLUP_ENABLE,
                        .pin_bit_mask = (1ULL << PIN_BUTTON) | (1ULL << PIN_DI_1) | (1ULL << PIN_DI_2)
                                        | (1ULL << PIN_DI_3) | (1ULL << PIN_DI_4)};   /* DI：內建上拉＋板上 10nF */
    gpio_config(&in);
    gpio_config_t rf = {.mode = GPIO_MODE_INPUT, .intr_type = GPIO_INTR_ANYEDGE, .pin_bit_mask = 1ULL << PIN_RF_DATA};
    gpio_config(&rf);
}

void app_main(void)
{
    esp_err_t err = nvs_flash_init();
    if (err == ESP_ERR_NVS_NO_FREE_PAGES || err == ESP_ERR_NVS_NEW_VERSION_FOUND) {
        ESP_ERROR_CHECK(nvs_flash_erase());
        err = nvs_flash_init();
    }
    ESP_ERROR_CHECK(err);

    gpio_setup();                              /* 繼電器腳先拉低，LEDC 接手前不會吸合 */
    coil_init();
    s_lock = xSemaphoreCreateMutex();
    s_relay_q = xQueueCreate(32, sizeof(fa_action_t));
    s_rf_q = xQueueCreate(256, sizeof(rf_edge_t));

    fa_io_cfg_t cfg;
    io_cfg_load(&cfg);
    fa_io_init(&s_io, &cfg);
    fa_relays_init_group(&s_relays, fa_io_interlock_mask(&cfg), CONFIG_FA_MAX_RELAYS_ON, CONFIG_FA_INTERLOCK_DEAD_MS);
    static const char *DI_NAME[] = {"全關", "按一次", "持續"}, *DO_NAME[] = {"自鎖", "點動", "互鎖"};
    for (int k = 0; k < FA_CH; k++)
        ESP_LOGI(TAG, "K%d：DI %s／DO %s（點動 %lums）", k + 1, DI_NAME[cfg.di_mode[k]], DO_NAME[cfg.do_mode[k]],
                 (unsigned long)cfg.jog_ms[k]);
    ESP_LOGI(TAG, "互鎖群組 0x%x；同時吸合上限 %d；Zigbee 發射 %ddBm", fa_io_interlock_mask(&cfg),
             CONFIG_FA_MAX_RELAYS_ON, CONFIG_FA_ZB_TX_POWER);
    remotes_load();
    name_load_save(false);

    xTaskCreate(relay_task, "relay", 3072, NULL, 6, NULL);
    xTaskCreate(rf_task, "rf", 3072, NULL, 4, NULL);
    xTaskCreate(ui_task, "ui", 3072, NULL, 3, NULL);
    gpio_install_isr_service(0);
    gpio_isr_handler_add(PIN_RF_DATA, rf_isr, NULL);
#if !CONFIG_FA_BOARD_V32
    static const fa_nfc_port_cb_t nfc_cb = {.get_cfg = nfc_get_cfg, .apply_cfg = nfc_apply_cfg, .get_status = nfc_get_status,
                                            .learn_remote = nfc_learn, .identify = nfc_identify,
                                            .factory_reset = nfc_factory_reset};
    fa_nfc_port_start(PIN_NFC_SDA, PIN_NFC_SCL, &nfc_cb);
#endif
    fa_zigbee_start(zb_on_set);
}

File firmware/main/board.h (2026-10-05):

/* WO_30109 腳位（hardware/…/WO30109_FreshAir.kicad_sch，scripts/design.py）。板子版本在 menuconfig 選 */
#pragma once
#include "sdkconfig.h"
#define PIN_RELAY_1   6    /* U1 pin6  → R5 → Q1 閘極（10k 下拉，開機不吸合） */
#define PIN_RELAY_2   7
#define PIN_RELAY_3   0
#define PIN_RELAY_4   1
/* J5 IN1–IN4 經 U5 TLP290-4：接通＝低電位（內建上拉）。V3.1 以前沒有 DI（那時 IO10/IO11 是指撥） */
#if CONFIG_FA_BOARD_V32
#define PIN_DI_1      22
#define PIN_DI_2      21
#define PIN_DI_3      20
#define PIN_DI_4      19
#else                      /* V3.3：DI 與 NFC I2C 照左右順序進 U1 上排（佈線不交叉） */
#define PIN_DI_1      3
#define PIN_DI_2      15   /* strapping 腳，但只在燒了 JTAG eFuse 時讀，出廠不受影響 */
#define PIN_DI_3      22
#define PIN_DI_4      21
#define PIN_NFC_SDA   20   /* U6 ST25DV04KC，R24 10k 上拉 */
#define PIN_NFC_SCL   19   /* R25 10k 上拉 */
#endif
#define PIN_BUTTON    9    /* B1，按下 = 低；也是 BOOT strapping 腳 */
#define PIN_LED       2    /* L1 藍燈，高電位亮 */
#define PIN_RF_DATA   23   /* SYN480R DO */

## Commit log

2026-10-02 feat: V1.3 原設計重繪為 KiCad 原理圖（基準線）
    - scripts/design.py：電路唯一來源（零件、腳位、網路）
    - scripts/gen_schematic.py：產生 .kicad_sch（標籤式連線）
    - hardware/lib：ZS3L、EPA09-4D 自訂符號；5 個自訂封裝（量測自原 Gerber）
    - ERC：0 error（4 個 1N4148W 庫版本 warning）
    [WO30109_FreshAir.kicad_sch]
2026-10-02 feat: V1.3 PCB 由原 Gerber 轉入 KiCad＋安規 DRC 規則
    - import_v13_pcb.py：走線/過孔照原樣、焊盤對齊放件、網路由銅箔連通推得
    - 原理圖 vs 銅箔 0 衝突、parity 0；S1 Mode_bit 依銅箔修正
    - .kicad_dru：市電↔SELV 6.4mm、市電間 2.5mm、板邊 0.5mm
    - V1.3 DRC：253 個市電↔低壓違規（重現原設計問題）
    [WO30109_FreshAir.kicad_pcb, WO30109_FreshAir.kicad_sch]
2026-10-02 feat(v2.0): 原理圖改版 — 保險絲/壓敏電阻、降壓電源、ZS3L UART
    - F1 T3.15A 慢斷保險絲（AC_L 入口）、RV1 07D471K 壓敏電阻
    - U4 LM1117 -> AP63203WU 3.3V 降壓（L2 3.9uH、C7/C13 22uF、C12 BST 100nF，依規格書 Table 2）
    - 12V 預算 146mA < IRM-02-12 167mA，保留原電源
    - ZS3L TXD->PA10、RXD<-PA9（USART1）、RST<-PB1(+R13 10k)；LED 改 PB0
    - NRST 電容 1uF->100nF、VDDA 加 C10 1uF、BOOT0 測試點 TP1
    - ERC 0 error
    [WO30109_FreshAir.kicad_sch]
2026-10-02 feat(v2.0): PCB 安規改版完成 — DRC 0 錯誤、全部接通
    PCB
    - 市電↔低壓 ≥6.4mm、市電網路間 ≥1.5mm、板邊 ≥0.5mm（.kicad_dru 規則）
    - 新增固定孔到市電 ≥2.3mm 規則；右緣市電走道外移、AC_N 在 H2 旁內彎（H2 0.85→2.85mm）
    - F1/RV1、AP63203 降壓、繼電器驅動、RF1/P2/S1 重新擺放；H1–H4 固定孔
    - 繼電器輸出 DO_* 由 mains_router 雙層格點佈線；低壓由 Freerouting，剩餘由 route_leftovers 補
    - GND 鋪銅依規則自動退讓；LCSC 料號不印絲印
    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
    [WO30109_FreshAir.kicad_pcb, WO30109_FreshAir.kicad_sch]
2026-10-02 ci: KiCad 容器改用 root 執行、actions 升 v5
    kicad/kicad 映像檔預設 user=kicad，checkout 寫不進 /__w/_temp 而失敗（EACCES）。
    zip 改用 python（映像檔不一定有 zip 指令）。
2026-10-02 feat: V2.0 設計驗證 — SPICE、PCB 計算器、熱、EMC、3D、kicadiff、Jobset
    - docs/verification/README.md：13 項驗證總表與逐項結果
    - sim/：ngspice 繼電器驅動（含拿掉續流二極體對照組）、LED 電流；CI 守門 Vds < 20V
    - GND 縫合過孔 90 顆（DRC 仍 0）
    - 自訂零件 3D 模型（OCP 產生 STEP）＋ assign_3d.py；正面最高 16.9mm
    - .kicad_jobset：KiCad 原生一鍵產出 8/8 成功
    - .kicad_pro MAINS 間距與 .kicad_dru 一致（1.5mm）
    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
    [WO30109_FreshAir.kicad_pcb]
2026-10-02 ci: 改用 kicad/kicad:10.0.6-full（含 3D 模型庫，版號與本機一致）
    原 kicad/kicad:10.0 沒有標準 3D 模型，STEP 裡 43 顆標準零件是空的。
2026-10-03 feat(v3.0): Tuya ZS3L＋EPA09-4D → ESP32-C6 單晶片＋SYN480R
    - U1 STM32F103＋U3 ZS3L → ESP32-C6-WROOM-1-N8（C5366877，Zigbee 3.0，JLC 有庫存）
    - RF1 EPA09-4D → SYN480R（C916347）＋13.52127MHz 晶振＋LC 匹配，韌體解 EV1527
    - B1 改 IO9（BOOT），P2 改 2×3 燒錄座；ANT1 433MHz 天線焊點
    - PCB 從 v2.0 標籤開始，只動低壓區；build_v30.sh 一鍵重建
    - 檢查：ERC 0 錯誤、DRC 0 錯誤、0 未連線、parity 0
    [WO30109_FreshAir.kicad_pcb, WO30109_FreshAir.kicad_sch]
2026-10-03 feat(v3.0.1): ESP32-C6 韌體、V3.0 驗證報告
    - firmware/：ESP-IDF v5.5.4 + esp-zigbee-lib 2.0.4；Zigbee 路由器 4 個 On/Off 端點、
    指撥 4 種模式與先斷後通互鎖、同時吸合上限 3（電源預算）、發射 +10dBm、
    EV1527 433 解碼與遙控器學習、按鍵／燈號
    - fa_core 純邏輯主機端單元測試 17 項（ASan/UBSan）；firmware-ci.yml 跑測試＋完整編譯
    - docs/verification/V3.0.md：電源預算、433 匹配模擬（sim/rf_match.cir）、EMC、BOM、Jobset
    - Jobset BOM 欄位空白（產出 0 位元組）修正
    - 檢查：idf.py build 0 警告；17/17 測試通過；ERC/DRC 0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
    [partitions.csv]
2026-10-03 docs: V3.0 已合併 main，更新版本狀態
2026-10-03 feat: make_jlc_files.py — JLC 下單檔（Gerber／BOM／CPL 含旋轉修正）
    [make_jlc_files.py]
2026-10-05 fix: CPL 角度改用 JLC 實際封裝驗證（背面 Q1–Q4、U4、S1 原本差 90°）
    matthewlai 規則表依封裝名稱比對，但 JLC 擺件用的是該 LCSC 料號自己的 EasyEDA
    封裝。在 JLC 下單頁 3D 檢視器核對 V3.0 CPL，背面 Q1–Q4（C5224182）、U4
    （C780769）、S1（C7421516）都差 90°。
    - jlc_footprints.json：BOM 26 種料號的 EasyEDA 焊盤座標快取
    - make_jlc_files.py：依焊盤編號求解角度（背面 = MirrorX·R(θ)·E，已實測），
    唯一解才採用，否則退回規則表並列出未驗證零件；--refresh-footprints、--check
    - test_make_jlc_files.py：6 個單元測試；KiCad CI 加 JLC 下單檔步驟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
    [make_jlc_files.py, test_make_jlc_files.py]
2026-10-05 hw: V3.1 433 匹配重新選值、續流改 B5819W（只換值不改佈線）
    - C15/C16 2.7pF（C162221）、L3 47nH（C29683）、L4 33nH（C35050）：規格書值以同系列
    Micrel 原廠輸入阻抗算峰值在 210–230MHz，新值 433.92MHz 失配 8–13dB → 3.1–5.3dB
    - D1–D4 1N4148W → B5819W（C8598，基礎料、同 SOD-123），配合 PWM 保持（Vf ≤0.4V）
    - sim/rf_match.cir 改用原廠阻抗、新舊值並排；scripts/rf_match_opt.py 最差情況選值
    - jlc_footprints.json 補新料號、刪舊料號；--refresh-footprints 預設只抓缺的
    - ERC 0、DRC 0、parity 0
    [WO30109_FreshAir.kicad_pcb, WO30109_FreshAir.kicad_sch]
2026-10-05 fw: 繼電器 PWM 降壓保持，取消同時吸合 ≤3 顆限制
    全壓 100ms（Omron G5Q-1 規定）後 LEDC 20kHz、60% 保持：12V 端每顆 33.3→14.4mA
    （sim/relay_pwm_hold.cir），4 顆最壞約 135mA < IRM-02-12 額定 167mA。
    - fa_coil：時序與電源預算（純 C）＋3 個主機單元測試（共 20 個）
    - app_main：LEDC＋esp_timer 切保持，回呼與關閉互斥
    - Kconfig：FA_RELAY_PWM_HOLD 等；上限預設 4；不安全組合編譯期 #error
    - CI：SPICE 守門保持電流 < 17mA、Vds < 20V
    [app_main.c, test_core.c]
2026-10-05 docs: V3.1 驗證報告、CHANGELOG、README
2026-10-05 docs: V3.1 JLC 網頁 PCBA 報價（5／10／30 片）
2026-10-05 hw: V3.2 4 路光耦 DI 輸入、拿掉指撥，上緣加長 10mm
    - J5 7P 3.5mm 插拔端子：+12V（R23 1.5k 限流，短路 8mA）／IN1–IN4／COM／GND
    - U5 TLP290-4 交流輸入光耦 ×4（乾接點、5–24VDC、NPN/PNP 都可），R15–R18 3.3k，C18–C21 10nF
    - DI1–4 → IO22/IO21/IO20/IO19（內建上拉）；S1 指撥拿掉
    - scripts/upgrade_v32_pcb.py：從 V3.1 PCB 重建，A* 佈新網路（不動既有走線、繞開 433 匹配區、
    長線自動試佈線順序、新區域縫合與孤島接回）
    - mains_router：stamp_r、keep_cl、封裝內建禁佈區、set_board（預設值維持舊行為）
    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
    [WO30109_FreshAir.kicad_pcb, WO30109_FreshAir.kicad_sch]
2026-10-05 fw: V3.2 DI／DO 模式、遙控器 4 鍵與 DI 同步、拿掉指撥
    - fa_io：DI（全關／按一次／持續）× DO（自鎖／點動／互鎖），固定 1 對 1；遙控器第 k 鍵＝DI k 分身
    - fa_relays：互鎖群組由 DO 模式決定（fa_relays_init_group）
    - app：DI 每 10ms 取樣（30ms 防彈跳）、每一幀遙控器送進 fa_io、NVS io_cfg、menuconfig 出廠預設
    - 主機測試 31/31；idf.py build 0 warning
2026-10-05 docs: V3.2 JLC 網頁 PCBA 報價（5／10／30 片）
2026-10-05 fix(V3.2): 板框改 L 形，P1（AC IN）前方維持原板緣
    第一版 V3.2 上緣整片加長 10mm，P1 開口朝板邊的插拔座前方多了一塊板子，
    插頭與 230V 電線會壓在低壓 GND 鋪銅上方（空氣間隙遠小於 6.4mm 加強絕緣）。
    DRC 只量銅箔間距，看不到插頭。改成只加長 J5 那一段（x 100–125.9），
    確認 P1 前方無走線、過孔、鋪銅；DRC 錯誤 0、未連線 0、parity 0。
    [WO30109_FreshAir.kicad_pcb]
2026-10-05 hw: V3.3 NFC 設定介面（ST25DV04KC＋板上印刷線圈），J5 改到左側板邊
    - U6 ST25DV04KC（C3304276，ISO 15693＋I2C）；L5 板上線圈 14.9×14.6mm 8 圈 1.277µH，
    C22 75pF（C1681）→ 13.84MHz，C24 微調空位；I2C SDA=IO20、SCL=IO19，10k 上拉
    - DI_1–4 改接 IO3/IO15/IO22/IO21（與 I2C 照左右順序排，佈線不交叉）
    - J5 直立貼左側板邊，左半段上緣到 107.2mm，左上角給線圈
    - upgrade_v32_pcb.py 以 WO_VER=3.2／3.3 切換；nfc_coil.py 以實際封裝銅箔算電感
    - mains_router：禁布區外擴半線寬、禁止鋪銅的禁布區也擋、讀真實 L 形板框
    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
    [WO30109_FreshAir.kicad_pcb, WO30109_FreshAir.kicad_sch]
2026-10-05 fw: NFC 設定介面（ST25DV04KC）、V3.3 腳位、App 協定規格與參考實作
    - fa_core/fa_nfc：STATE／REQUEST／ACK 格式、gen 樂觀鎖、HMAC 簽章、mailbox 指令（challenge 防重送）
    - fa_core/fa_sha256：SHA-256／HMAC（FIPS 180-2、RFC 4231 向量）
    - ST25DV 的 RF 密碼 I2C 端無法設定（規格書 Table 60）→ 改由 ESP32 驗簽；每台 8 位數 PIN 存 NVS
    - main/st25dv.c：I2C 驅動（16-byte 分列＋ACK polling、I2C 密碼開 FTM、mailbox）
    - main/fa_nfc_port.c：每 100ms 輪詢；app_main 套用設定時互鎖分組變了先全關
    - board.h：menuconfig 選 V3.3／V3.2；V3.3 DI=IO3/IO15/IO22/IO21、NFC I2C=IO20/IO19
    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
2026-10-05 fix(V3.3): NFC 線圈禁布區允許焊盤（CI 的 KiCad 會把線圈自己最內圈的焊盤判成違規）
    本機 KiCad 10.0.6（PPA）豁免封裝自己的焊盤、CI 容器（kicad/kicad:10.0.6-full）不豁免，
    同一份板檔 CI 報 items_not_allowed。線圈禁布區本來就不需要禁止焊盤（那裡不放零件），
    改成只禁鋪銅與過孔，兩邊都通過。
    [WO30109_FreshAir.kicad_pcb]
2026-10-05 docs: V3.3 JLC 網頁 PCBA 報價（5／10／30 片）
2026-10-05 hw: V3.4 照外殼 4-02-3 放回原板框（DI 2.54mm、NFC 外接 FPC 天線）
    外殼是精鋼塑模 4-02-3（35mm 導軌盒 88×72×59，螺絲 50×50）；原板 63.4×83.08 本來就是照它做的。
    V3.2／V3.3 加高的板子放不進外殼，V3.3 的板上 NFC 線圈離前蓋 >50mm 讀不到。
    - J5 改 KF2EDGR-2.54-7P（C577599），和 P1 共用上方開窗，焊盤離市電 9.08mm
    - NFC 板上線圈拿掉，J6（JST SH 2P，C160388）接 FPC 天線；C22/C24 依天線電感調諧（不上件）
    - P2 改背面 2×3 燒錄測試點；B1 改 TS-1088（C720477 基礎料）放 J5 後方
    - build_v34.sh：從 V3.1 換件擺件，低壓全部 Freerouting 重佈（第一輪即 0 未連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
    [WO30109_FreshAir.kicad_pcb, WO30109_FreshAir.kicad_sch]
2026-10-05 docs: V3.4 JLC 網頁 PCBA 報價（5／10／30 片）
